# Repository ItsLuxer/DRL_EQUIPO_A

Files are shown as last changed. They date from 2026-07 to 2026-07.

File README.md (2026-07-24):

# 🚀 DRL Equipo A

¡Hola! 😁 Somos estudiantes del **Centro de Enseñanza Técnica Industrial (CETI)**, actualmente cursando la asignatura de **Control I**.

<p align="justify">
El objetivo principal de este proyecto es el diseño y construcción de un sistema aéreo no tripulado (dron) desde cero. Para fundamentar el desarrollo y comprender la integración de sus subsistemas, hemos iniciado este proceso mediante la ingeniería inversa de un dron comercial. Este análisis técnico nos ha permitido identificar, documentar y comprender la arquitectura, los componentes electrónicos y los protocolos de comunicación críticos necesarios para el funcionamiento y control de vuelo de un dron.
</p>

## 🛠 Equipo de Gestión y Desarrollo

Este proyecto es posible gracias al trabajo colaborativo del siguiente equipo de ingenieros:

* **Ingeniero Control:** José Eduardo
* **Ingeniero Mecánico:** Héctor Manuel
* **Ingeniero Eléctrico:** Héctor Cruz
* **Ingeniero Software:** José Alberto
* **Ingeniero Comunicaciones:** Darío Ibarra

---

# 📄 Prototipo

<div align="center">
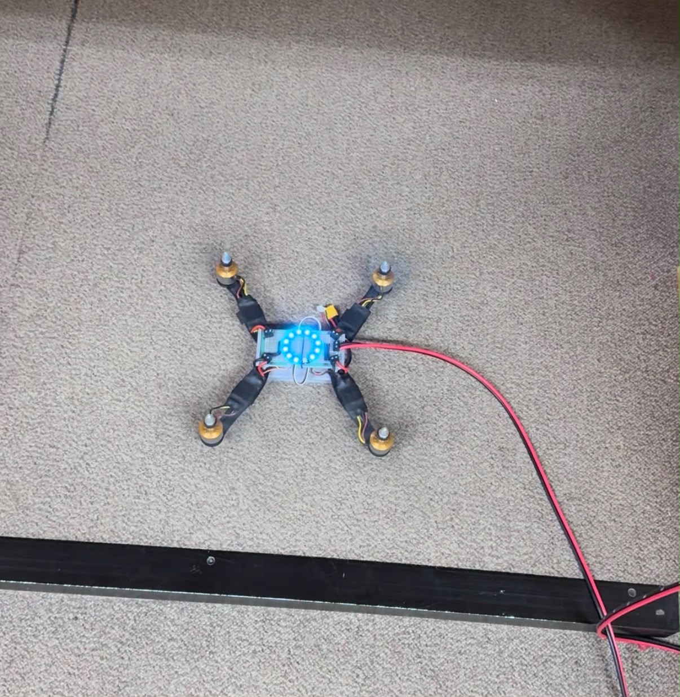
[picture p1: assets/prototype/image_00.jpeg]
  
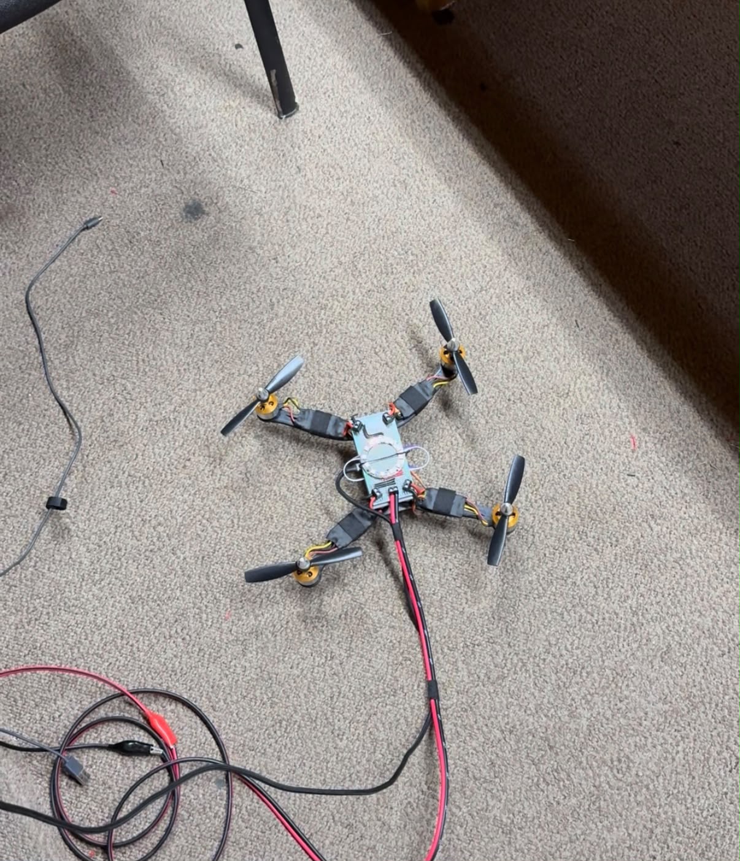
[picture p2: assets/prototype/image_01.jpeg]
  
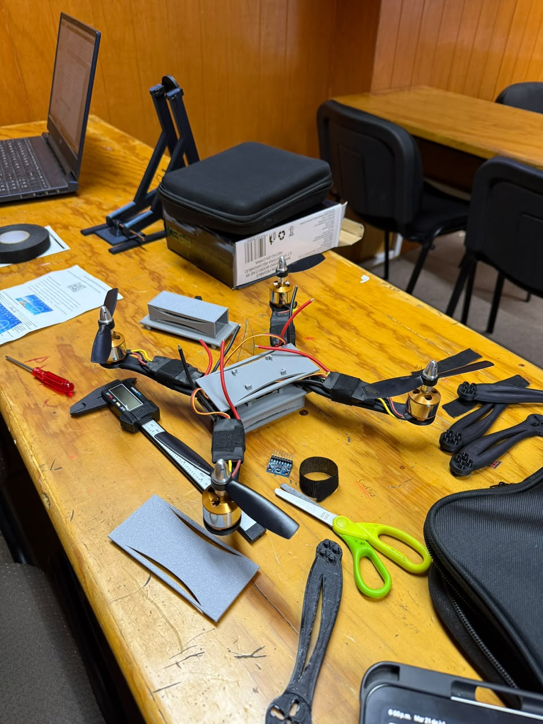
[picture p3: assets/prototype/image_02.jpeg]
  
</div>

---

# 🔩 Componentes del Dron

A continuación se documentan los componentes electrónicos y mecánicos utilizados en el desarrollo del prototipo propio.

<table>
  <tr>
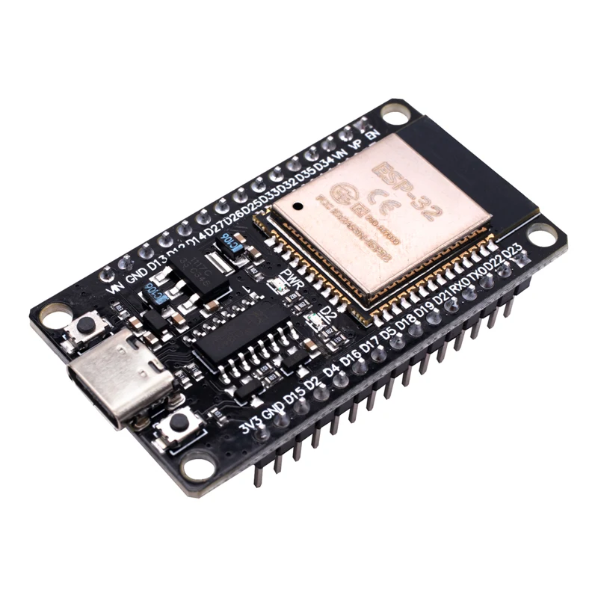
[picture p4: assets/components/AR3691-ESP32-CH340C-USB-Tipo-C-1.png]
    <td align="center" width="250"></td>
    <td>
      <b>ESP32 - Base</b><br>
      <ul>
        <li><b>Modelo:</b> ESP32 DEVKIT V1</li>
        <li><b>Puerto:</b> Micro USB o USB-C (según versión)</li>
        <li><b>Chip USB-Serial:</b> CP2102 (Micro USB) / CH340 (USB-C)</li>
        <li><b>Núcleos:</b> 2 (Tensilica Xtensa 32-bit LX6)</li>
        <li><b>Frecuencia de reloj:</b> hasta 240 MHz</li>
        <li><b>Desempeño:</b> hasta 600 DMIPS</li>
        <li><b>Voltaje de alimentación (USB):</b> 5 V DC</li>
        <li><b>Voltaje de E/S:</b> 3.3 V DC</li>
        <li><b>Consumo en modo suspensión:</b> 5 µA</li>
        <li><b>Pines físicos:</b> 30 (24 GPIO digitales)</li>
        <li><b>ADC:</b> 2 canales de 12 bits (SAR), hasta 18 canales</li>
        <li><b>Conectividad:</b> WiFi 802.11 b/g/n/e/i (150 Mbit/s @ 2.4 GHz) + Bluetooth 4.2 BR/EDR/BLE, antena en PCB</li>
        <li><b>Memoria:</b> 448 KB ROM, 520 KB SRAM, 6 KB SRAM RTC, soporte QSPI multi-chip</li>
        <li><b>Seguridad:</b> IEEE 802.11 (WFA, WPA/WPA2, WAPI), cifrado por hardware AES, SHA-2, RSA, ECC, RNG</li>
        <li><b>Dimensiones:</b> 52 mm x 28.5 mm x 15 mm</li>
        <li><b>Peso:</b> 9 g</li>
      </ul>
    </td>
  </tr>
  <tr>
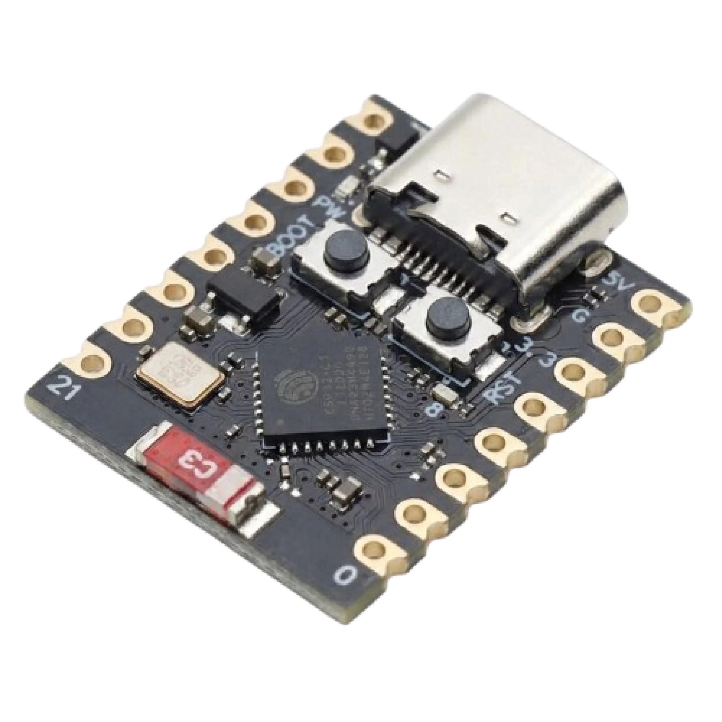
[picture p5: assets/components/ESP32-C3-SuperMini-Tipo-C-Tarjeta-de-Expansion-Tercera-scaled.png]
    <td align="center" width="250"></td>
    <td>
      <b>ESP32 - Aire</b><br>
      <ul>
        <li><b>Modelo:</b> ESP32-C3 Super Mini</li>
        <li><b>Chip:</b> ESP32-C3, 32-bit RISC-V, 160 MHz</li>
        <li><b>Puerto:</b> USB Tipo C</li>
        <li><b>Voltaje de operación:</b> 3 V a 3.6 V</li>
        <li><b>Rango de temperatura:</b> -40° a 85°C</li>
        <li><b>WiFi:</b> IEEE 802.11 b/g/n (2.4 GHz)</li>
        <li><b>Bluetooth:</b> Bluetooth 5, Bluetooth Mesh</li>
        <li><b>Memoria:</b> 384 KB ROM, 400 KB SRAM, 4 MB flash</li>
        <li><b>Periféricos:</b> 1× I2C, 1× SPI, 2× UART, 11× PWM, 4× ADC</li>
        <li><b>Dimensiones:</b> 22.5 mm × 18 mm</li>
        <li><b>Peso:</b> 3.05 g</li>
      </ul>
    </td>
  </tr>
  <tr>
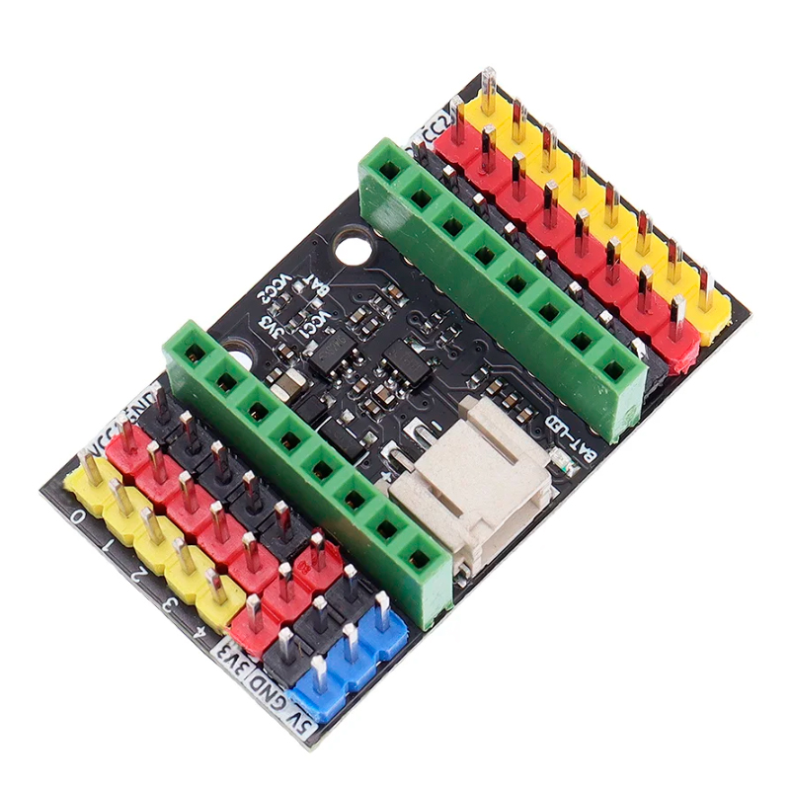
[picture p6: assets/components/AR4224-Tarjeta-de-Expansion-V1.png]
    <td align="center" width="250"></td>
    <td>
      <b>Tarjeta de Expansión</b><br>
      <ul>
        <li><b>Entrada/Fuente:</b> USB Tipo C / Batería de Litio 3.7 V</li>
        <li><b>Voltajes de salida:</b> 5 V y 3.3 V</li>
        <li><b>Voltaje de batería:</b> 3.7 V</li>
        <li><b>Dimensiones:</b> 37.4 mm × 22.7 mm</li>
        <li><b>Peso:</b> 8 g</li>
      </ul>
    </td>
  </tr>
  <tr>
    <td align="center" width="250"></td>
    <td>
      <b>Motor Brushless</b><br>
      <ul>
        <li><b>Modelo:</b> A2212/6 T</li>
        <li><b>Motor KV (RPM / V):</b> KV2200</li>
        <li><b>RPM / V:</b> 2200 KV (2200 revoluciones por minuto por cada volt suministrado)</li>
        <li><b>Voltaje:</b> 7.2 V a 12 V</li>
        <li><b>Corriente:</b> 12 A / 60 s</li>
        <li><b>Eficiencia máxima:</b> 80%</li>
        <li><b>Corriente máxima de eficiencia:</b> 4 ~ 10 A (> 75%)</li>
        <li><b>Corriente sin carga:</b> 10 V / 0.5 A</li>
        <li><b>Tamaño de motor (con eje):</b> 27.5 mm x 38.5 mm</li>
        <li><b>Diámetro del eje:</b> 3.17 mm (3.2 mm)</li>
        <li><b>Longitud del diámetro:</b> 11.5 mm</li>
        <li><b>Peso:</b> 47 g</li>
      </ul>
    </td>
  </tr>
  <tr>
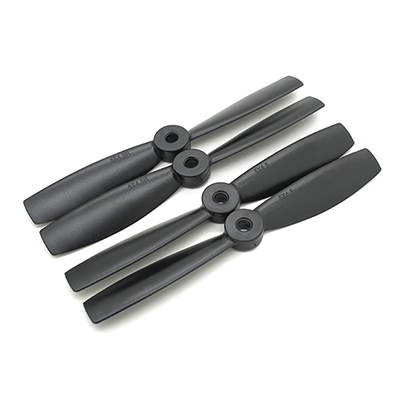
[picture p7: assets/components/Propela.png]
    <td align="center" width="250"></td>
    <td>
      <b>Propela</b><br>
      <ul>
        <li><b>Color:</b> Negro</li>
        <li><b>Orificio de eje:</b> 5 mm</li>
        <li><b>Configuración del paquete:</b> 4 piezas (2 CW / 2 CCW)</li>
        <li><b>Dimensiones:</b> 5 x 4.5"</li>
        <li><b>Peso:</b> 3.8 g c/u</li>
      </ul>
    </td>
  </tr>
  <tr>
    <td align="center" width="250"></td>
    <td>
      <b>ESC</b><br>
      <ul>
        <li><b>Modelo:</b> ESC 30A Driver Motor Brushless</li>
        <li><b>Voltaje de entrada:</b> 2–4 celdas de litio o 5–12 celdas NiCd/NiMH</li>
        <li><b>Corriente continua:</b> 30 A</li>
        <li><b>Corriente máxima (ráfaga):</b> 40 A</li>
        <li><b>Salida BEC:</b> 5 V / 2 A</li>
        <li><b>Frecuencia de trabajo:</b> 50–60 Hz (señal PWM)</li>
        <li><b>RPM máximas soportadas:</b> 210,000 RPM (2 polos), 70,000 RPM (6 polos), 35,000 RPM (12 polos)</li>
        <li><b>Señal de control:</b> PWM estándar (1000–2000 µs)</li>
        <li><b>Tamaño:</b> 57 mm × 25 mm × 8 mm</li>
        <li><b>Peso neto:</b> 27 g</li>
      </ul>
    </td>
  </tr>
  <tr>
    <td align="center" width="250"></td>
    <td>
      <b>Batería</b><br>
      <ul>
        <li><b>Voltaje:</b> 11.1 V</li>
        <li><b>Celdas:</b> 3S</li>
        <li><b>Capacidad de descarga:</b> 30 a 60C</li>
        <li><b>Corriente:</b> 1,400 mAh</li>
        <li><b>Descarga continua:</b> 25C</li>
        <li><b>Tamaño:</b> 85.7 mm x 29.8 mm x 20.2 mm</li>
        <li><b>Peso neto:</b> 125 g</li>
      </ul>
    </td>
  </tr>
  <tr>
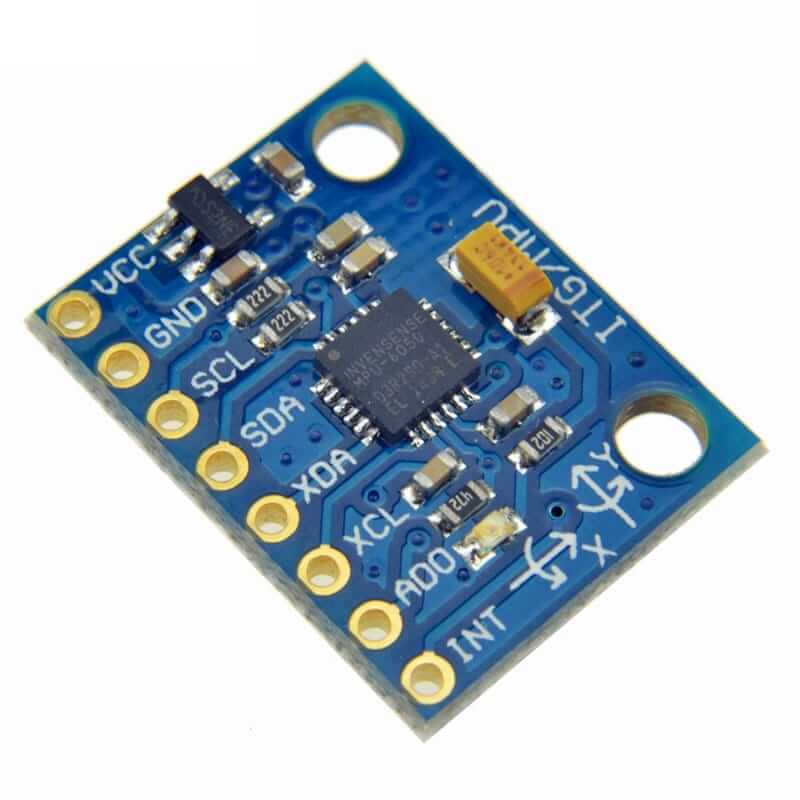
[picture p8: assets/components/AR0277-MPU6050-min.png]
    <td align="center" width="250"></td>
    <td>
      <b>Módulo Giroscopio/Acelerómetro</b><br>
      <ul>
        <li><b>Módulo:</b> MPU6050 6 Grados de libertad.</li>
        <li><b>Voltaje de funcionamiento:</b> 3.3 V a 5 V</li>
        <li><b>Chip:</b> MPU-6050</li>
        <li><b>Grados de libertad (DoF):</b> 6</li>
        <li><b>Protocolo de comunicación:</b> I2C</li>
        <li><b>Convertidor analógico a digital:</b> 16 bits en todos los ejes</li>
        <li><b>Rangos:</b>
          <ul>
            <li><b>Giroscopio:</b> ±250, ±500, ±1000 y ±2000 °/s (dps)</li>
            <li><b>Acelerómetro:</b> ±2, ±4, ±8 y ±16 g</li>
          </ul>
        </li>
        <li><b>Dimensiones:</b> 40 mm x 25 mm x 5 mm</li>
        <li><b>Peso:</b> 3 g</li>
      </ul>
    </td>
  </tr>
  <tr>
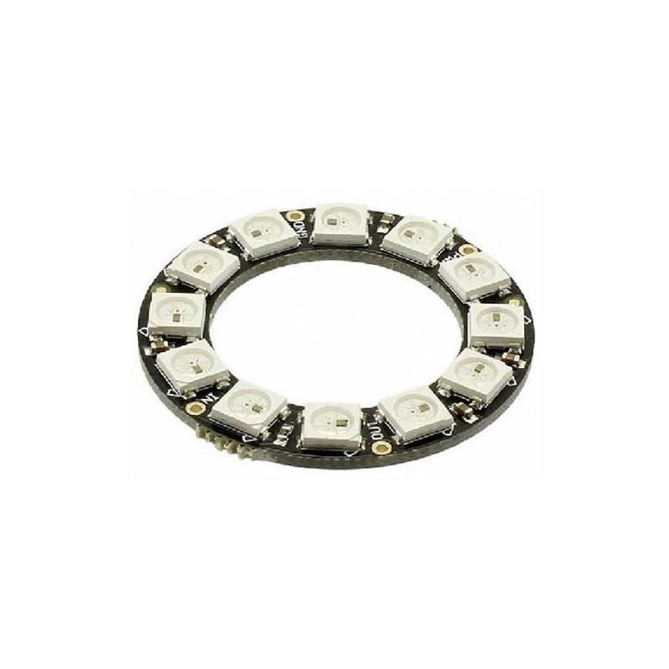
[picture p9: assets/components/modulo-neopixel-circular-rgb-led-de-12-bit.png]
    <td align="center" width="250"></td>
    <td>
      <b>Iluminación Neopixel</b><br>
      <ul>
        <li><b>Chip controlador:</b> WS2812B</li>
        <li><b>Voltaje de operación:</b> 5 V</li>
        <li><b>Número de LEDs:</b> 12 piezas</li>
        <li><b>Consumo por píxel:</b> 18 mA</li>
        <li><b>Velocidad de transmisión de datos:</b> hasta 800 Kbps</li>
        <li><b>Colores por píxel:</b> 16,777,216 (256 niveles por canal RGB)</li>
        <li><b>Frecuencia de escaneo:</b> ≥ 400 Hz/s</li>
        <li><b>Interfaz:</b> cascada en serie (una línea de señal)</li>
        <li><b>Distancia de transmisión entre puntos:</b> < 5 m sin circuito adicional</li>
        <li><b>Protección:</b> polaridad inversa integrada</li>
        <li><b>Diámetro interior:</b> 35.5 mm</li>
        <li><b>Diámetro exterior:</b> 50 mm</li>
        <li><b>Peso:</b> 6 g</li>
      </ul>
    </td>
  </tr>
</table>

---

## 📄 Planos

A continuación se documentan los planos técnicos utilizados en el desarrollo del prototipo.

<div align="center">

### Plano del Chasis


### Distribución de Componentes


</div>

---

# 🚁 Compilación de Betaflight 4.5.2 para STM32F411 (BlackPill)

**Objetivo:** Compilar un firmware funcional de Betaflight 4.5.2 para una placa de desarrollo genérica STM32F411 (BlackPill) en un entorno Windows utilizando MSYS2, evitando errores de estructura de directorios y dependencias de Python.

---

## 📋 Requisitos Previos
1. Sistema operativo **Windows**.
2. Entorno **MSYS2** instalado.
3. Consola **UCRT64** de MSYS2 abierta. Todo el proceso se realizará exclusivamente en esta terminal.

---

## 🛠️ Paso 1: Preparación del entorno y dependencias
Antes de descargar el código, es necesario asegurar que el sistema cuenta con todas las herramientas necesarias para la compilación y la ejecución de scripts internos.

```bash
# 1. Actualizar el sistema base de MSYS2
pacman -Syu

# 2. Instalar Git, Make, Unzip y Python3
pacman -S git make unzip python3
```

---

## 📥 Paso 2: Descarga del código fuente de Betaflight
Crearemos un directorio de trabajo limpio en la raíz del disco duro y descargaremos la versión exacta del código que vamos a compilar.

```bash
# 1. Navegar a la raíz y crear la carpeta de trabajo
cd /c/
mkdir betaflight
cd betaflight

# 2. Clonar el repositorio oficial (incluyendo submódulos)
git clone --recursive https://github.com/betaflight/betaflight.git betaflight-4.5.2

# 3. Entrar a la carpeta descargada
cd betaflight-4.5.2

# 4. Cambiar a la rama de la versión estable 4.5.2
git checkout -b release-4.5.2 tags/4.5.2
```

---

## ⚙️ Paso 3: Instalación de la cadena de herramientas (ARM SDK)
Betaflight requiere una versión específica del compilador GCC cruzado para arquitecturas ARM. Descargaremos esta herramienta y ajustaremos su directorio.

```bash
# 1. Descargar y extraer el compilador GCC ARM automáticamente
make arm_sdk_install

# 2. Corregir el error de anidación de carpetas (mover archivos un nivel arriba)
mv tools/gcc-arm-none-eabi-10.3-2021.10/gcc-arm-none-eabi-10.3-2021.10/* tools/gcc-arm-none-eabi-10.3-2021.10/

# 3. Añadir el compilador a las variables de entorno (PATH)
export PATH=$PATH:/c/betaflight/betaflight-4.5.2/tools/gcc-arm-none-eabi-10.3-2021.10/bin
```

---

## 📂 Paso 4: Obtención de la configuración personalizada
Para que Betaflight reconozca la placa BlackPill, necesitamos un perfil de hardware (target) que defina los pines y puertos de la STM32F411.

```bash
# 1. Salir momentáneamente a la carpeta principal de trabajo
cd /c/betaflight

# 2. Clonar el repositorio comunitario con la configuración de la placa
git clone https://github.com/anlgncr/custom-betaflight-board.git
```

---

## 🧩 Paso 5: Integración en la estructura de Betaflight 4.5+
A partir de la versión 4.5, el sistema de compilación cambió. Las configuraciones de hardware ya no se ubican en `src/main/target`, sino que utilizan el sistema de configuración unificado.

```bash
# 1. Regresar a la carpeta del código fuente de Betaflight
cd betaflight-4.5.2

# 2. Crear el directorio para configuraciones personalizadas (si no existe)
mkdir -p src/config/configs

# 3. Copiar la configuración de la BlackPill a la nueva ruta
cp -r /c/betaflight/custom-betaflight-board/BLACKPILL src/config/configs/
```

---

## 🚀 Paso 6: Compilación del Firmware
Con el entorno limpio, el compilador configurado y la placa en la ruta correcta, procederemos a compilar.

> ⚠️ **Importante:** En la versión 4.5.2, para compilar configuraciones personalizadas, se debe utilizar el parámetro `CONFIG=` en lugar del antiguo `TARGET=`.

```bash
# 1. Limpiar el entorno de compilaciones o cachés anteriores
make clean

# 2. Iniciar la compilación final para la BlackPill
make CONFIG=BLACKPILL
```

---

## 🎉 Paso 7: Resultados y Flasheo
Si el proceso se realizó correctamente, la terminal finalizará sin errores y mostrará el uso de memoria (FLASH y RAM) del procesador. El archivo compilado listo para ser cargado en la placa se generará en la siguiente ruta:

```
/c/betaflight/betaflight-4.5.2/obj/betaflight_4.5.2_STM32F411_BLACKPILL.hex
```

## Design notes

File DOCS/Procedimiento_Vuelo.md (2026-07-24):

# Procedimiento de vuelo — Daltonics_Vuelo (despegue/aterrizaje por tecla)

Firmware Aire: `Firmware/Daltonics_Vuelo/Daltonics_Vuelo.ino` (ESP32-C3 SuperMini)
Firmware Tierra: `Firmware/Daltonics_Tierra/Daltonics_Tierra.ino` (con telemetría al operador)
Mando: `CONTROL/Control_Vuelo_Daltonics.m` (MATLAB)

**Telemetría**: el dron reporta a MATLAB a 10 Hz su roll/pitch, gas, modo y alertas
(emergencia, IMU caída, aterrizado) — se ve en la ventana del mando como "DRON >>".
El viejo `ESP32_PRUEBATIERRA` sigue sirviendo como respaldo, pero sin telemetría.

## Máquina de estados (campo A de la trama)

| A | Estado | Motores | LED |
|---|---|---|-----|
| 0 | DESARMADO | Apagados | Verde tenue |
| 1 | IDLE | Girando suave (1120 µs), sin despegar | Verde brillante |
| 2 | VUELO | Rampa 8 %/s hasta gas de hover + PID de actitud | Azul |
| 3 | ATERRIZAJE | Rampa automática -3.5 %/s hasta idle | Amarillo → celeste |
| — | EMERGENCIA (>45° de inclinación) | Apagados hasta desarmar (Q) y rearmar | Rojo |
| — | FAILSAFE (>500 ms sin señal) | Apagados | Naranja |

## Teclas (MATLAB)

`E` armar/idle · `T` despegue · `L` aterrizar · `Q` corte total ·
`W/S` trim de gas ±0.5 % · flechas roll/pitch · `A/D` yaw · `ESPACIO` nivelar

## Secuencia de esta noche

1. **Alimentación**: usar la **LiPo real**. La fuente de banco se cae de amperaje y
   puede resetear el ESP32 **con los motores armados**. Si igual usás la fuente,
   solo pruebas SIN hélices.
2. Encender el dron **quieto y nivelado**: al arrancar hace 3 s de calibración del
   giroscopio (LED violeta). No moverlo hasta que termine.
3. Espera los beeps de los ESC (LED ámbar, pulso mínimo 3 s).
4. **Prueba SIN hélices** (obligatoria la primera vez):
   - `E` → los 4 motores giran parejos en idle. Si uno no arranca, recalibrar ESCs.
   - `T` → inclinar el dron a mano y ver por Serial que el motor del lado que baja
     **sube** de PWM. Si es al revés, corregir signos antes de poner hélices.
   - `L` y `Q` → verificar rampa de bajada y corte.
5. **Primera prueba con hélices**: dron sujetado (banco o correas), a baja altura,
   sin gente cerca del plano de las hélices.
6. En hover, ajustar el gas con `W/S`: el 45 % inicial se midió con la fuente
   dudosa, así que el valor real con LiPo puede ser distinto.

## Ajuste del PID (en orden, sin hélices primero)

1. Subir `Kp_ang` hasta que empuje de regreso con fuerza al inclinar, sin oscilar.
2. Si tiembla al soltar, subir `Kd_ang`.
3. Solo al final, si queda "recostado", subir `Ki_ang` de a poco.

## Sin altímetro

El hover mantiene el dron **nivelado**, pero la altura es lazo abierto: deriva con
la batería descargándose. Compensar con `W/S`. Siguiente mejora sugerida: montar el
BME680 o un VL53L0X para lazo cerrado de altura.

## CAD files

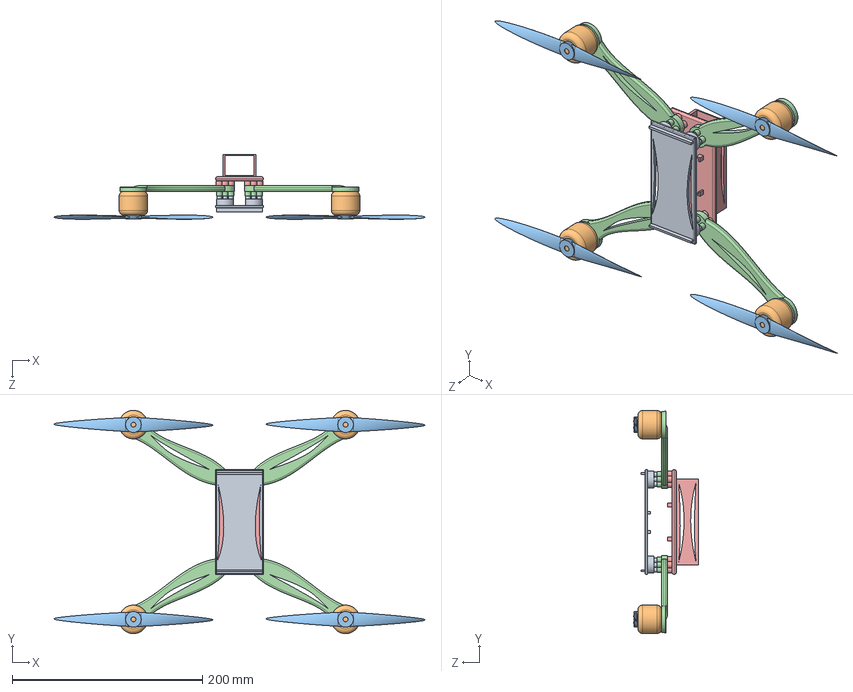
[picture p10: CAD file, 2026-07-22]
Dron semana 3 Mejorado/Ensamblaje Dron semana 3.SLDASM
389.7 x 234.5 x 67.9 mm
Molde de la base Dron semana 3
Brazos del dron semana 3 x 2
Elises de 16 cm x 4
molde del Motor x 4
Segundo piso

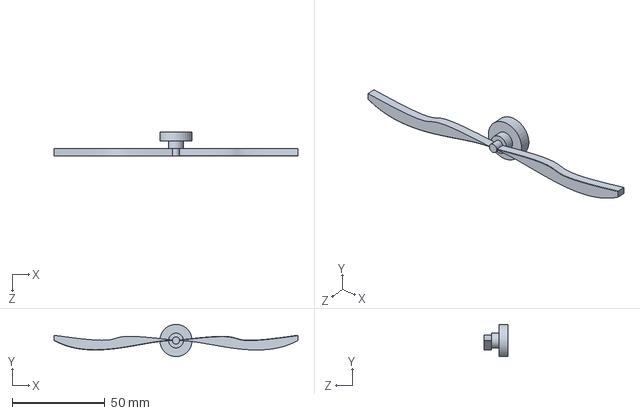
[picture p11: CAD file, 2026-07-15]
Diseños MK1/Dron Simulacion para Matlap/Elises.SLDPRT
131.6 x 17.4 x 13.0 mm

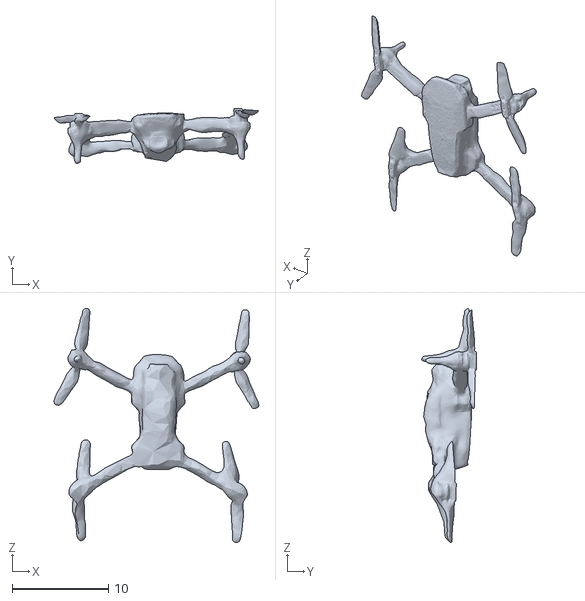
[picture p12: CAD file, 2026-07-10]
Dron_Digital/MATLAB_DRIVE/DronNaya.STL
21.3 x 5.76 x 24.4

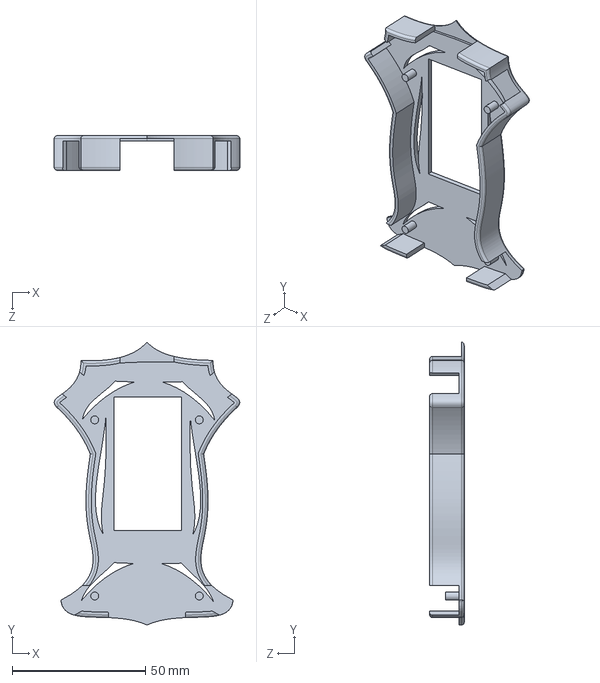
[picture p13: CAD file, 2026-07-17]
Estructura base/FRONTPANEL.SLDPRT
69.7 x 106.3 x 13.0 mm

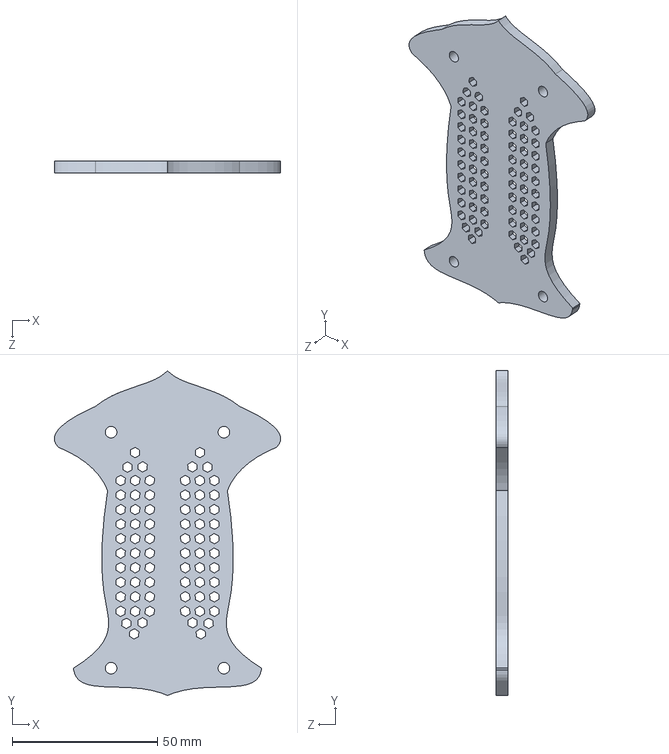
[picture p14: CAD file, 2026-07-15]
Diseños MK1/Dron Simulacion para Matlap/DronSimulacion.SLDPRT
77.9 x 111.8 x 4.00 mm

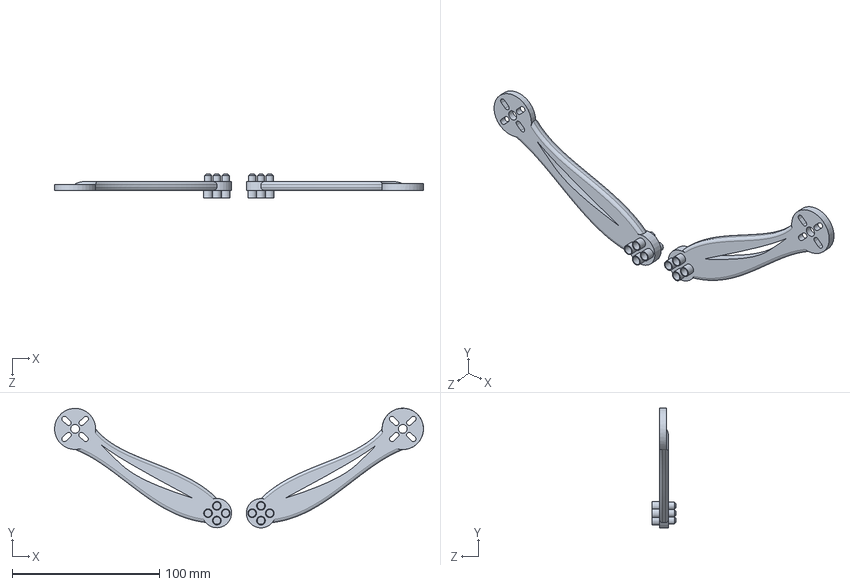
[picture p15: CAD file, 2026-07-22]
Dron semana 3 Mejorado/Brazos del dron semana 3.SLDPRT
250.9 x 81.4 x 16.0 mm

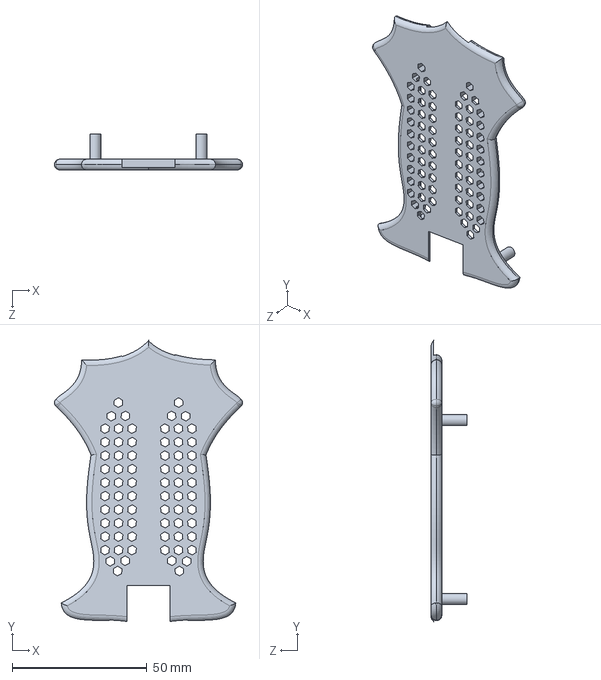
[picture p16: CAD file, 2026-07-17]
Estructura base/Prueba 2.SLDPRT
69.7 x 104.1 x 13.3 mm

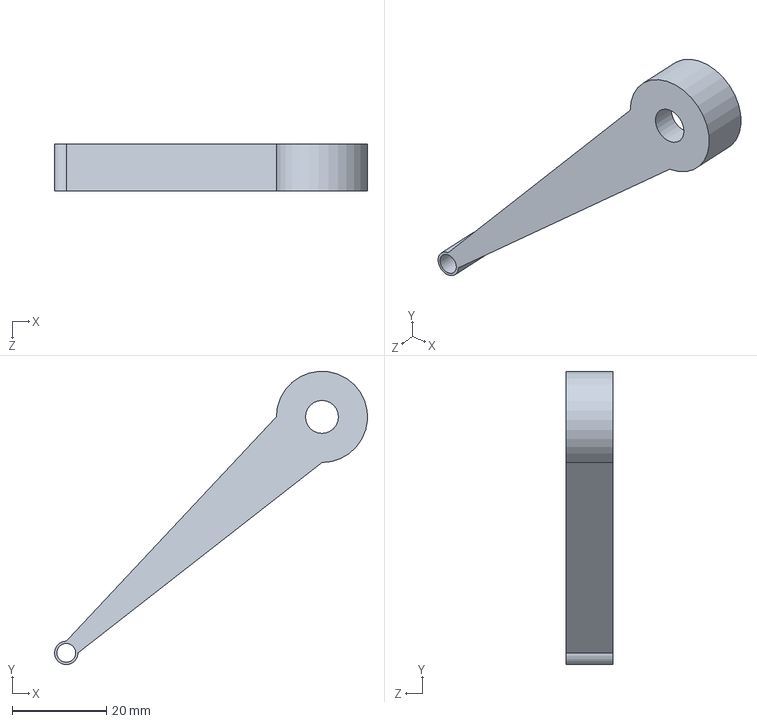
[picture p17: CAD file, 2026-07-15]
Diseños MK1/Dron Simulacion para Matlap/Brazos del dron.SLDPRT
66.5 x 62.3 x 10.0 mm

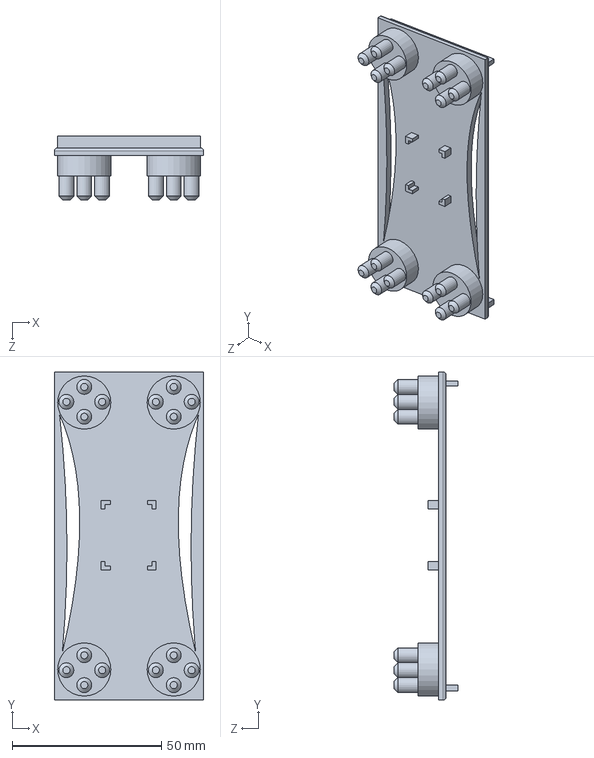
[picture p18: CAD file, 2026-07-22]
Dron semana 3 Mejorado/Segundo piso.SLDPRT
50.0 x 110.0 x 21.5 mm

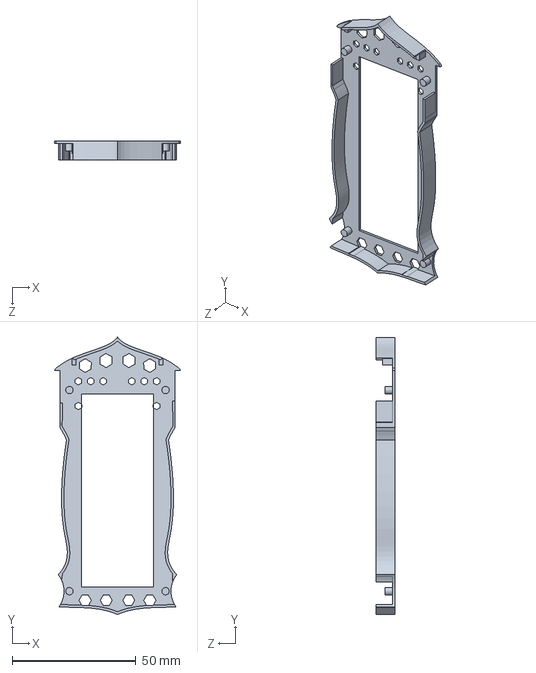
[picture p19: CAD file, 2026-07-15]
Diseños MK1/Dron Simulacion para Matlap/DrpnBASE.SLDPRT
51.0 x 111.8 x 7.60 mm

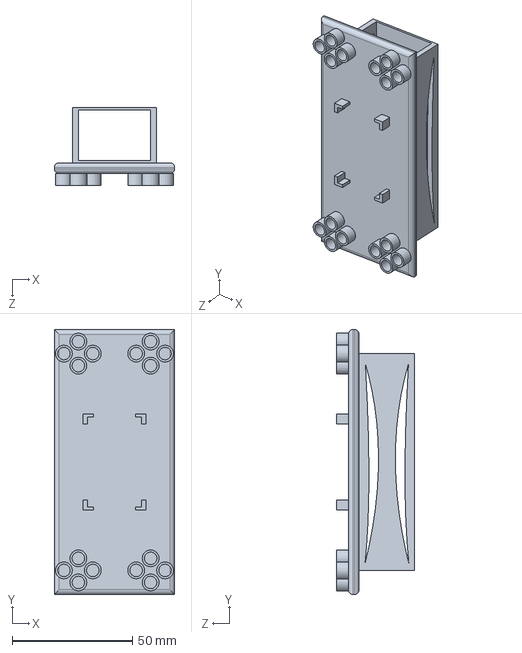
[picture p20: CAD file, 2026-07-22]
Dron semana 3 Mejorado/Molde de la base Dron semana 3.SLDPRT
50.0 x 110.0 x 32.5 mm

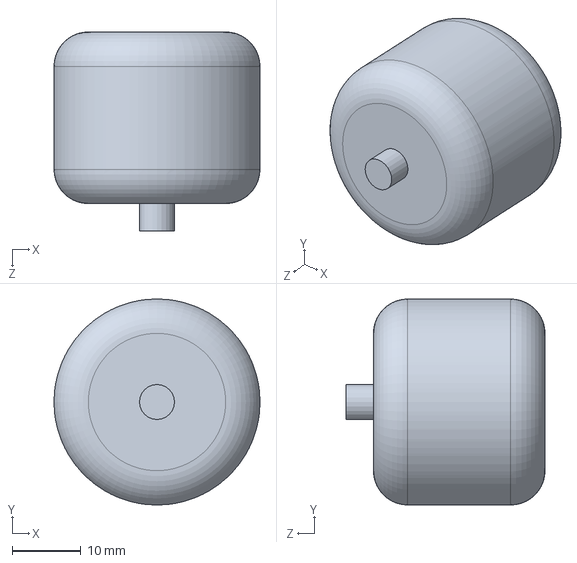
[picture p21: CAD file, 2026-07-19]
Dron semana 3 Mejorado/molde del Motor.SLDPRT
30.0 x 30.0 x 29.0 mm

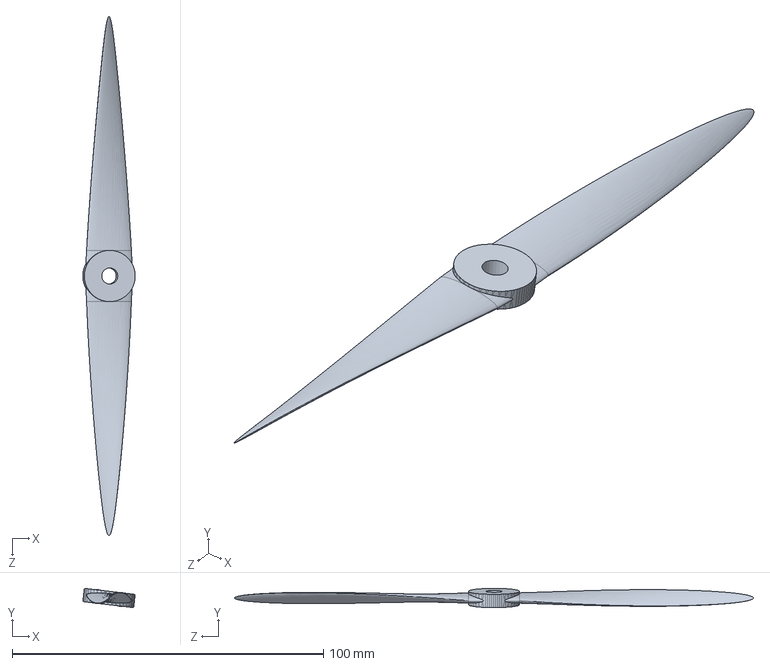
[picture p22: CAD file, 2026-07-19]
Dron semana 3 Mejorado/Elises de 16 cm.SLDPRT
16.9 x 6.21 x 166.8 mm

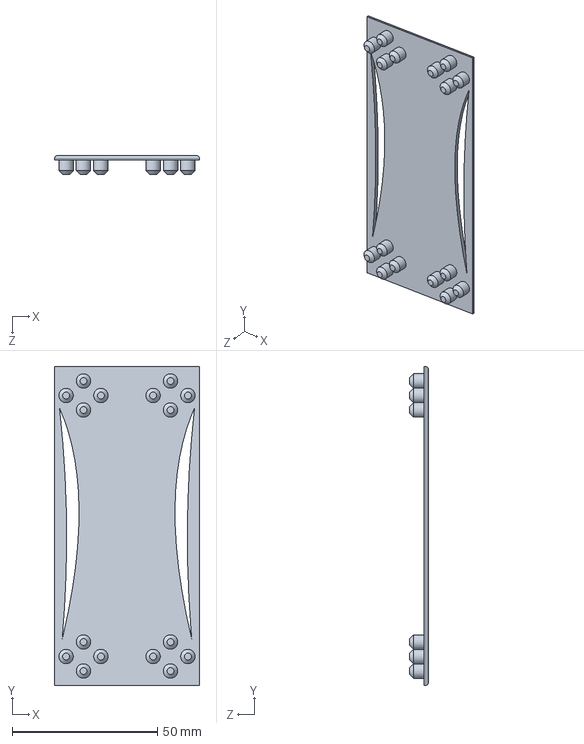
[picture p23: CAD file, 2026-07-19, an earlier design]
Dron Semana 3/Segundo piso.SLDPRT
50.0 x 110.0 x 6.50 mm

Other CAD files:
Dron Semana 3/Ensamblaje Dron semana 3.SLDASM
Dron Semana 3/Molde de la base Dron semana 3.SLDPRT
Dron Semana 3/Brazos del dron semana 3.SLDPRT

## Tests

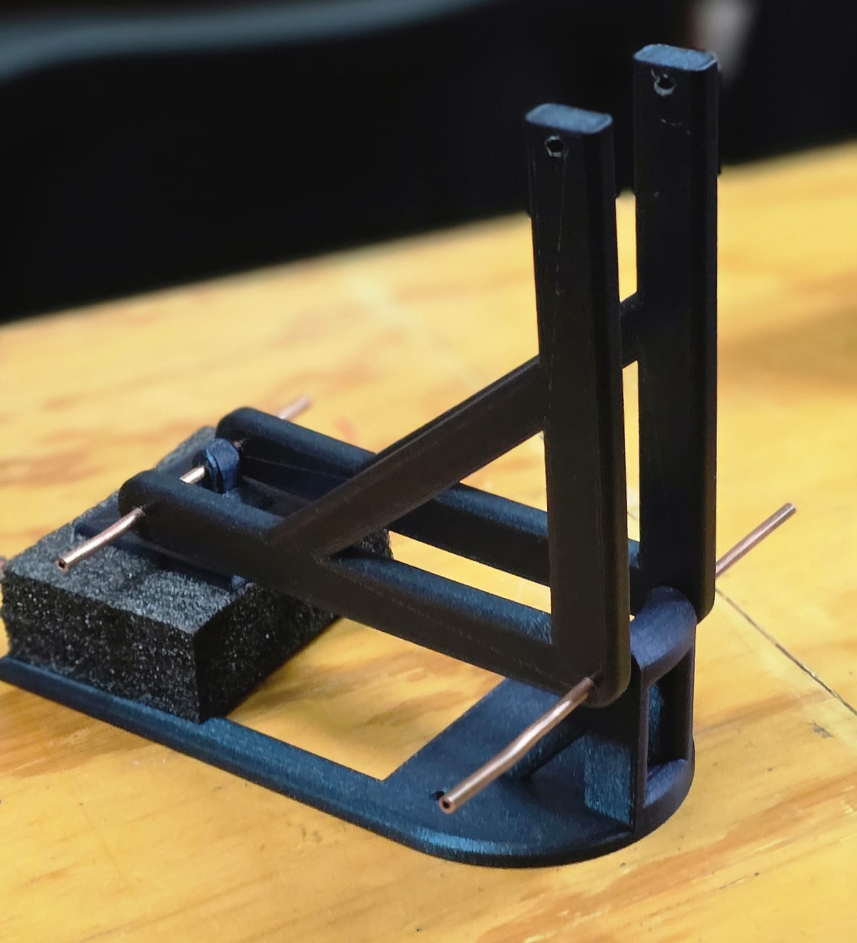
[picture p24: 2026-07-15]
Banco de Pruebas para los motores del dron/Banco de Prubeas.jpeg

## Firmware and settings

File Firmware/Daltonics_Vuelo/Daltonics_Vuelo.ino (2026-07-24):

// =========================================================================
// Daltonics_Vuelo.ino — Firmware de vuelo con MAQUINA DE ESTADOS
// (ESP32-C3 SuperMini, unidad AIRE — Escuderia Daltonics)
//
// Evolucion de Daltonics_Aire.ino. Agrega:
//   1) Calibracion automatica del giroscopio al encender (bias) — el dron
//      DEBE estar quieto y nivelado durante los primeros ~3 segundos.
//   2) Maquina de estados comandada desde tierra por el campo A del
//      protocolo (antes solo 0/1, ahora 0-3):
//        A=0  DESARMADO   -> motores apagados
//        A=1  IDLE        -> motores girando suave (IDLE_US) SIN despegar
//        A=2  VUELO       -> despegue con rampa suave hacia el throttle
//                            de hover + PID de actitud (se queda nivelado)
//        A=3  ATERRIZAJE  -> rampa descendente automatica hasta idle
//   3) Rampa (slew-rate) de throttle: nunca hay saltos bruscos de gas.
//
// PROTOCOLO: mismo PaqueteControl de siempre. ESP32_PRUEBATIERRA.ino NO
// necesita cambios (su parser del campo A ya acepta 0-3). En tierra usar
// CONTROL/Control_Vuelo_Daltonics.m (teclas E/T/L/Q).
//
// *** SIN ALTIMETRO: el hover mantiene NIVEL (roll/pitch) pero la ALTURA
// *** es lazo abierto. El gas de hover se ajusta fino con W/S desde
// *** MATLAB. Primera prueba: sosten el dron con la mano (lejos de las
// *** helices) o atado, a baja altura, y con la LiPo real — la fuente de
// *** banco puede resetear el ESP32 con los motores armados.
//
// Checklist antes de volar (una sola vez):
//   1) Calibrar ESCs (Firmware/Calibrar_ESCs).
//   2) SIN HELICES: armar (E), inclinar a mano y confirmar por Serial que
//      el motor del lado que baja es el que SUBE de PWM.
//   3) Verificar que IDLE_US hace girar los 4 motores parejos sin empuje.
// =========================================================================

#include <Arduino.h>
#include <WiFi.h>
#include <esp_now.h>
#include <ESP32Servo.h>
#include <Adafruit_NeoPixel.h>
#include <Wire.h>
#include <Adafruit_MPU6050.h>
#include <Adafruit_Sensor.h>

// ================= PROTOCOLO =================
struct __attribute__((packed)) PaqueteControl {
    uint16_t throttle;   // 1000-2000 us (en VUELO: gas objetivo de hover)
    uint16_t roll;       // 1000-2000 us, centro 1500
    uint16_t pitch;      // 1000-2000 us, centro 1500
    uint16_t yaw;        // 1000-2000 us, centro 1500 (yaw-RATE)
    uint8_t  armable;    // MODO: 0=desarmado 1=idle 2=vuelo 3=aterrizaje
};

enum Modo : uint8_t { M_DESARMADO = 0, M_IDLE = 1, M_VUELO = 2, M_ATERRIZAJE = 3 };

PaqueteControl comandosDron = {1000, 1500, 1500, 1500, M_DESARMADO};
unsigned long ultimaVezRecibido = 0;
const unsigned long TIMEOUT_FAILSAFE = 500; // ms sin señal -> failsafe

// ================= TELEMETRIA HACIA TIERRA (dron -> operador) =================
// El dron aprende el MAC de Tierra del primer paquete recibido y le manda
// su estado a 10 Hz. Tierra lo reenvia por USB a MATLAB como "TL,...".
struct __attribute__((packed)) PaqueteTelemetria {
    float   rollDeg;   // actitud estimada
    float   pitchDeg;
    float   thrPct;    // gas aplicado ahora (thrActual)
    uint8_t modo;      // 0-3
    uint8_t flags;     // b0=emergencia b1=failsafe b2=aterrizado b3=mpuOK
};
uint8_t macTierra[6];
volatile bool macTierraCapturada = false;
bool peerTierraListo = false;
unsigned long ultimoTelem = 0;

void onDataRecv(const esp_now_recv_info_t *recv_info, const uint8_t *incomingData, int len) {
    if (len == sizeof(PaqueteControl)) {
        memcpy(&comandosDron, incomingData, sizeof(comandosDron));
        ultimaVezRecibido = millis();
        if (!macTierraCapturada) {
            memcpy(macTierra, recv_info->src_addr, 6);
            macTierraCapturada = true;
        }
    }
}

// ================= MPU6050 (pines C3 SuperMini) =================
#define SDA_PIN 20
#define SCL_PIN 21
Adafruit_MPU6050 mpu;
bool mpuOK = false;

// Bias del giroscopio, medido en la calibracion de arranque
float gyroBiasX = 0, gyroBiasY = 0, gyroBiasZ = 0;
bool imuCalibrada = false;

// ================= NEOPIXEL =================
#define PIN_NEOPIXEL 10
#define NUM_LEDS 12
Adafruit_NeoPixel aro(NUM_LEDS, PIN_NEOPIXEL, NEO_GRB + NEO_KHZ800);

// ================= MOTORES (pines/desfases confirmados) =================
Servo motor1, motor2, motor3, motor4;
const int pinM1 = 1, pinM2 = 2, pinM3 = 3, pinM4 = 4;
// M1=delantero-izq  M2=delantero-der  M3=trasero-izq  M4=trasero-der

int desfaseM1 = -25;
int desfaseM2 = 0;
int desfaseM3 = 0;
int desfaseM4 = 0;

const int PWM_MIN_US  = 1000;
const int PWM_MAX_US  = 2000;
const int IDLE_US     = 1120;  // motores girando suave, SIN empuje de despegue
                               // (ajustar: debe girar parejo en los 4 sin que
                               //  el dron "aligere" sobre el piso)

// ================= RAMPAS DE THROTTLE (en % de gas, 0-100) =================
const float RAMPA_SUBIDA_PCT_S  = 8.0f;   // despegue: sube 8%/s (susave)
const float RAMPA_BAJADA_PCT_S  = 12.0f;  // correccion hacia abajo en vuelo
const float RAMPA_ATERR_PCT_S   = 3.5f;   // aterrizaje: baja 3.5%/s
const float PCT_CORTE_ATERR     = 25.0f;  // debajo de esto ya no sustenta ->
                                          // corta a idle (aterrizado)
float thrActual = 0.0f;                    // % de gas aplicado ahora mismo
bool  aterrizado = false;                  // subestado de M_ATERRIZAJE

// ================= GEOMETRIA / EMPUJE (igual que Daltonics_Aire) =================
float DX   = 0.1061f;
float DY   = 0.1061f;
float TMAX = 2.73f;
float CYAW = 0.013f;

// ================= GANANCIAS PID =================
// Punto de partida CONSERVADOR (~mitad del gemelo digital) para el primer
// contacto real: mejor blando que sobre-corregir y voltear.
//
// GANANCIAS DEL GEMELO DIGITAL (DALTONICS_parametros.m, tuneadas en
// simulacion para el dron de 530 g) — meta a la que subir gradualmente
// si la prueba de banco sin helices responde sana:
//   Kp_ang = 0.077   Ki_ang = 0.019   Kd_ang = 0.023   N = 40
//   Kp_yaw = 0.052   Ki_yaw = 0.022
// Orden de tuneo: Kp primero, Kd si oscila, Ki al final y de a poco
// (si se activa Ki, agregar limite al integrador / anti-windup).
float Kp_ang = 0.035f, Ki_ang = 0.0f, Kd_ang = 0.010f, N_filt = 20.0f;
float Kp_yaw = 0.020f, Ki_yaw = 0.0f;

// ================= PID 2-DOF (roll/pitch) y PI (yaw-rate) =================
struct PID2DOF {
    float Kp, Ki, Kd, N;
    float integ = 0, dFilt = 0, prevMeas = 0;
    bool primed = false;
    float update(float ref, float meas, float dt) {
        if (!primed) { prevMeas = meas; primed = true; }
        float error = ref - meas;
        integ += Ki * error * dt;
        float rawDeriv = (meas - prevMeas) / dt;
        dFilt += (rawDeriv - dFilt) * constrain(N * dt, 0.0f, 1.0f);
        prevMeas = meas;
        return Kp * error + integ - Kd * dFilt;
    }
    void reset() { integ = 0; dFilt = 0; primed = false; }
};

struct PIControlador {
    float Kp, Ki;
    float integ = 0;
    float update(float ref, float meas, float dt) {
        float error = ref - meas;
        integ += Ki * error * dt;
        return Kp * error + integ;
    }
    void reset() { integ = 0; }
};

PID2DOF pidRoll, pidPitch;
PIControlador pidYaw;

// ================= ESTIMACION DE ACTITUD =================
float rollEst = 0, pitchEst = 0; // rad
const float ALPHA = 0.98f;

// ================= MEZCLADORA =================
float Mix[4][4];

void invertir4x4(float A[4][4], float Inv[4][4]) {
    float aug[4][8];
    for (int i = 0; i < 4; i++) {
        for (int j = 0; j < 4; j++) aug[i][j] = A[i][j];
        for (int j = 0; j < 4; j++) aug[i][4 + j] = (i == j) ? 1.0f : 0.0f;
    }
    for (int col = 0; col < 4; col++) {
        int piv = col;
        for (int r = col + 1; r < 4; r++)
            if (fabs(aug[r][col]) > fabs(aug[piv][col])) piv = r;
        if (piv != col) for (int j = 0; j < 8; j++) { float t = aug[col][j]; aug[col][j] = aug[piv][j]; aug[piv][j] = t; }
        float d = aug[col][col];
        for (int j = 0; j < 8; j++) aug[col][j] /= d;
        for (int r = 0; r < 4; r++) {
            if (r == col) continue;
            float f = aug[r][col];
            for (int j = 0; j < 8; j++) aug[r][j] -= f * aug[col][j];
        }
    }
    for (int i = 0; i < 4; i++)
        for (int j = 0; j < 4; j++) Inv[i][j] = aug[i][4 + j];
}

void construirMezcladora() {
    float A[4][4] = {
        { 1,     1,     1,     1   },
        { DY,   -DY,    DY,   -DY  },
        {-DX,   -DX,    DX,    DX  },
        {-CYAW,  CYAW,  CYAW, -CYAW}
    };
    invertir4x4(A, Mix);
}

float mapFloat(float x, float inMin, float inMax, float outMin, float outMax) {
    return (x - inMin) * (outMax - outMin) / (inMax - inMin) + outMin;
}

// ================= SETPOINTS =================
void leerSetpoints(float &thrPct, float &rollRef, float &pitchRef, float &yawRateRef) {
    thrPct     = constrain(map(comandosDron.throttle, 1000, 2000, 0, 100), 0, 100);
    rollRef    = (constrain((int)comandosDron.roll,  1000, 2000) - 1500) / 500.0f * 25.0f  * DEG_TO_RAD;
    pitchRef   = (constrain((int)comandosDron.pitch, 1000, 2000) - 1500) / 500.0f * 25.0f  * DEG_TO_RAD;
    yawRateRef = (constrain((int)comandosDron.yaw,   1000, 2000) - 1500) / 500.0f * 120.0f * DEG_TO_RAD;
}

// ================= CORTE POR INCLINACION EXTREMA =================
const float DANGER_ANGLE_RAD = 45.0f * DEG_TO_RAD;
const int   DANGER_DEBOUNCE = 25; // ~100ms a 250Hz
int contadorPeligro = 0;
bool emergencia = false; // requiere desarmar (A=0) desde tierra para limpiar

// ---------------------------------------------------------------------
void aplicarPWM(int m1, int m2, int m3, int m4) {
    motor1.writeMicroseconds(constrain(m1, PWM_MIN_US, PWM_MAX_US) + desfaseM1);
    motor2.writeMicroseconds(constrain(m2, PWM_MIN_US, PWM_MAX_US) + desfaseM2);
    motor3.writeMicroseconds(constrain(m3, PWM_MIN_US, PWM_MAX_US) + desfaseM3);
    motor4.writeMicroseconds(constrain(m4, PWM_MIN_US, PWM_MAX_US) + desfaseM4);
}

void apagarMotores() {
    motor1.writeMicroseconds(PWM_MIN_US);
    motor2.writeMicroseconds(PWM_MIN_US);
    motor3.writeMicroseconds(PWM_MIN_US);
    motor4.writeMicroseconds(PWM_MIN_US);
}

void motoresIdle() {
    aplicarPWM(IDLE_US, IDLE_US, IDLE_US, IDLE_US);
}

// ================= CALIBRACION IMU AL ARRANQUE =================
// El dron debe estar QUIETO y NIVELADO. Promedia el giroscopio para sacar
// el bias, e inicializa rollEst/pitchEst con el acelerometro para que el
// filtro complementario no arranque desde cero si el piso no es perfecto.
void calibrarIMU() {
    const int N = 500;
    float sx = 0, sy = 0, sz = 0;
    sensors_event_t acc, gyr, temp;

    Serial.println("Calibrando IMU... NO MUEVAS EL DRON (3 s)");
    for (int i = 0; i < N; i++) {
        mpu.getEvent(&acc, &gyr, &temp);
        sx += gyr.gyro.x; sy += gyr.gyro.y; sz += gyr.gyro.z;
        // LED: barrido violeta mientras calibra
        if (i % 40 == 0) {
            aro.clear();
            aro.setPixelColor((i / 40) % NUM_LEDS, aro.Color(140, 0, 255));
            aro.show();
        }
        delay(5);
    }
    gyroBiasX = sx / N; gyroBiasY = sy / N; gyroBiasZ = sz / N;

    mpu.getEvent(&acc, &gyr, &temp);
    rollEst  = atan2(acc.acceleration.y, acc.acceleration.z);
    pitchEst = atan2(-acc.acceleration.x,
                      sqrt(acc.acceleration.y * acc.acceleration.y +
                           acc.acceleration.z * acc.acceleration.z));
    imuCalibrada = true;
    aro.clear(); aro.show();
    Serial.printf("IMU calibrada. Bias gyro [rad/s]: %.4f %.4f %.4f | roll0:%.1f pitch0:%.1f deg\n",
                  gyroBiasX, gyroBiasY, gyroBiasZ, rollEst * RAD_TO_DEG, pitchEst * RAD_TO_DEG);
}

// ================= INICIALIZACION DE ESCs =================
// Manda minimo sostenido para que los ESC armen (beeps) antes de aceptar
// cualquier modo. Los motores quedan LISTOS pero parados.
void inicializarESCs() {
    Serial.println("Inicializando ESCs (pulso minimo 3 s)...");
    unsigned long t0 = millis();
    while (millis() - t0 < 3000) {
        apagarMotores();
        // LED: barrido ambar
        aro.clear();
        aro.setPixelColor(((millis() - t0) / 250) % NUM_LEDS, aro.Color(255, 150, 0));
        aro.show();
        delay(20);
    }
    aro.clear(); aro.show();
    Serial.println("ESCs listos.");
}

// ---------------------------------------------------------------------
unsigned long ultimoDebug = 0;
unsigned long tPrevControl = 0;

void setup() {
    Serial.begin(115200);
    delay(500);

    // --- ESP-NOW primero ---
    WiFi.mode(WIFI_STA);
    WiFi.disconnect();
    if (esp_now_init() != ESP_OK) {
        Serial.println("Error critico: no se pudo inicializar ESP-NOW");
    }
    esp_now_register_recv_cb(onDataRecv);

    // --- NeoPixel ---
    aro.begin();
    aro.setBrightness(60);

    // --- ESCs: attach y secuencia de inicializacion ---
    motor1.attach(pinM1, PWM_MIN_US, PWM_MAX_US);
    motor2.attach(pinM2, PWM_MIN_US, PWM_MAX_US);
    motor3.attach(pinM3, PWM_MIN_US, PWM_MAX_US);
    motor4.attach(pinM4, PWM_MIN_US, PWM_MAX_US);
    inicializarESCs();

    // --- IMU + calibracion ---
    Wire.begin(SDA_PIN, SCL_PIN);
    mpuOK = mpu.begin();
    if (!mpuOK) {
        Serial.println("Error: MPU6050 no detectado. NO se podra armar.");
    } else {
        mpu.setAccelerometerRange(MPU6050_RANGE_8_G);
        mpu.setFilterBandwidth(MPU6050_BAND_10_HZ);
        calibrarIMU();
    }

    // --- PID / mezcladora ---
    pidRoll.Kp = Kp_ang;  pidRoll.Ki = Ki_ang;  pidRoll.Kd = Kd_ang;  pidRoll.N = N_filt;
    pidPitch.Kp = Kp_ang; pidPitch.Ki = Ki_ang; pidPitch.Kd = Kd_ang; pidPitch.N = N_filt;
    pidYaw.Kp = Kp_yaw;   pidYaw.Ki = Ki_yaw;
    construirMezcladora();

    Serial.println("Daltonics_Vuelo listo. Esperando modo desde Tierra:");
    Serial.println("  A=1 idle | A=2 despegue/hover | A=3 aterrizaje | A=0 desarmado");
    tPrevControl = micros();
}

// ---------------------------------------------------------------------
void loop() {
    unsigned long ahora = micros();
    float dt = (ahora - tPrevControl) / 1e6f;
    tPrevControl = ahora;
    if (dt <= 0 || dt > 0.5f) dt = 0.004f;

    // --- Failsafe: sin señal -> estado seguro (motores fuera) ---
    bool senalPerdida = (millis() - ultimaVezRecibido) > TIMEOUT_FAILSAFE;
    if (senalPerdida) {
        comandosDron.throttle = 1000;
        comandosDron.roll = 1500; comandosDron.pitch = 1500; comandosDron.yaw = 1500;
        comandosDron.armable = M_DESARMADO;
    }

    Modo modo = (Modo)comandosDron.armable;
    if (modo > M_ATERRIZAJE) modo = M_DESARMADO; // valor corrupto -> seguro

    // --- Reset de emergencia: tierra debe pasar por A=0 ---
    if (modo == M_DESARMADO) { emergencia = false; }

    // --- Leer IMU y estimar actitud (con bias restado) ---
    float yawRateMeas = 0;
    if (mpuOK) {
        sensors_event_t acc, gyr, temp;
        mpu.getEvent(&acc, &gyr, &temp);

        float gx = gyr.gyro.x - gyroBiasX;
        float gy = gyr.gyro.y - gyroBiasY;
        float gz = gyr.gyro.z - gyroBiasZ;

        float accelRoll  = atan2(acc.acceleration.y, acc.acceleration.z);
        float accelPitch = atan2(-acc.acceleration.x,
                                  sqrt(acc.acceleration.y * acc.acceleration.y +
                                       acc.acceleration.z * acc.acceleration.z));
        rollEst  = ALPHA * (rollEst  + gx * dt) + (1 - ALPHA) * accelRoll;
        pitchEst = ALPHA * (pitchEst + gy * dt) + (1 - ALPHA) * accelPitch;
        yawRateMeas = gz;

        if (fabs(rollEst) > DANGER_ANGLE_RAD || fabs(pitchEst) > DANGER_ANGLE_RAD) {
            contadorPeligro++;
            if (contadorPeligro >= DANGER_DEBOUNCE && (modo == M_VUELO || modo == M_ATERRIZAJE)) {
                emergencia = true;
                Serial.println("¡PELIGRO! Inclinacion extrema -> motores apagados.");
            }
        } else {
            contadorPeligro = 0;
        }
    }

    // --- Setpoints ---
    float thrCmdPct, rollRef, pitchRef, yawRateRef;
    leerSetpoints(thrCmdPct, rollRef, pitchRef, yawRateRef);

    bool puedeVolar = mpuOK && imuCalibrada && !senalPerdida && !emergencia;

    // =================== MAQUINA DE ESTADOS ===================
    if (!puedeVolar || modo == M_DESARMADO) {
        // ---------- DESARMADO / EMERGENCIA / FAILSAFE ----------
        apagarMotores();
        thrActual = 0;
        aterrizado = false;
        pidRoll.reset(); pidPitch.reset(); pidYaw.reset();

        if (emergencia)        aro.fill(aro.Color(255, 0, 0));   // rojo
        else if (senalPerdida) aro.fill(aro.Color(255, 60, 0));  // naranja
        else if (!mpuOK || !imuCalibrada) aro.fill(aro.Color(255, 0, 255)); // magenta
        else                   aro.fill(aro.Color(0, 40, 0));    // verde tenue

    } else if (modo == M_IDLE) {
        // ---------- IDLE: motores girando, sin despegar ----------
        motoresIdle();
        thrActual = (IDLE_US - PWM_MIN_US) / 10.0f; // % equivalente al idle
        aterrizado = false;
        pidRoll.reset(); pidPitch.reset(); pidYaw.reset();
        aro.fill(aro.Color(0, 255, 60)); // verde brillante = armado en idle

    } else {
        // ---------- VUELO (A=2) o ATERRIZAJE (A=3) ----------
        float thrObjetivo;
        if (modo == M_VUELO) {
            aterrizado = false;
            thrObjetivo = thrCmdPct; // gas objetivo desde tierra (hover +/- trim W/S)
        } else { // M_ATERRIZAJE
            if (thrActual <= PCT_CORTE_ATERR) aterrizado = true;
            thrObjetivo = aterrizado ? (IDLE_US - PWM_MIN_US) / 10.0f : 0.0f;
        }

        // Rampa de throttle (slew-rate)
        float maxSubida, maxBajada;
        if (modo == M_ATERRIZAJE && !aterrizado) {
            maxSubida = 0;                            // aterrizando no se sube
            maxBajada = RAMPA_ATERR_PCT_S * dt;
        } else {
            maxSubida = RAMPA_SUBIDA_PCT_S * dt;
            maxBajada = RAMPA_BAJADA_PCT_S * dt;
        }
        float delta = thrObjetivo - thrActual;
        if (delta >  maxSubida) delta =  maxSubida;
        if (delta < -maxBajada) delta = -maxBajada;
        thrActual += delta;

        if (modo == M_ATERRIZAJE && aterrizado) {
            // Ya toco piso (o gas bajo el minimo de sustentacion): idle
            motoresIdle();
            pidRoll.reset(); pidPitch.reset(); pidYaw.reset();
            aro.fill(aro.Color(0, 120, 255)); // celeste = aterrizado, en idle
        } else {
            // PID de actitud activo (en aterrizaje se mantiene nivelado
            // mientras baja: refs de roll/pitch siguen viniendo de tierra,
            // que en ese modo manda 0)
            float tauX = pidRoll.update(rollRef, rollEst, dt);
            float tauY = pidPitch.update(pitchRef, pitchEst, dt);
            float tauZ = pidYaw.update(yawRateRef, yawRateMeas, dt);

            float Ftotal = thrActual * (4.0f * TMAX / 100.0f);
            float u[4] = {Ftotal, tauX, tauY, tauZ};
            float T[4];
            for (int i = 0; i < 4; i++) {
                T[i] = Mix[i][0]*u[0] + Mix[i][1]*u[1] + Mix[i][2]*u[2] + Mix[i][3]*u[3];
                T[i] = constrain(T[i], 0.0f, TMAX);
            }
            int pulso[4];
            for (int i = 0; i < 4; i++)
                pulso[i] = (int)constrain(mapFloat(T[i], 0.0f, TMAX, PWM_MIN_US, PWM_MAX_US), PWM_MIN_US, PWM_MAX_US);
            aplicarPWM(pulso[0], pulso[1], pulso[2], pulso[3]);

            if (modo == M_VUELO) aro.fill(aro.Color(0, 150, 255));  // azul = volando
            else                 aro.fill(aro.Color(255, 255, 0));  // amarillo = aterrizando
        }
    }
    aro.show();

    // --- Telemetria hacia Tierra ~10 Hz ---
    if (macTierraCapturada && !peerTierraListo) {
        esp_now_peer_info_t peer = {};
        memcpy(peer.peer_addr, macTierra, 6);
        peer.channel = 0;
        peer.encrypt = false;
        if (esp_now_add_peer(&peer) == ESP_OK) peerTierraListo = true;
    }
    if (peerTierraListo && millis() - ultimoTelem > 100) {
        ultimoTelem = millis();
        PaqueteTelemetria tl;
        tl.rollDeg  = rollEst * RAD_TO_DEG;
        tl.pitchDeg = pitchEst * RAD_TO_DEG;
        tl.thrPct   = thrActual;
        tl.modo     = (uint8_t)modo;
        tl.flags    = (emergencia ? 1 : 0) | (senalPerdida ? 2 : 0) |
                      (aterrizado ? 4 : 0) | (mpuOK ? 8 : 0);
        esp_now_send(macTierra, (uint8_t *)&tl, sizeof(tl));
    }

    // --- Debug ~10 Hz ---
    if (millis() - ultimoDebug > 100) {
        ultimoDebug = millis();
        Serial.printf("MODO:%d FS:%d EMG:%d ATZ:%d | thr:%.1f%% obj:%.1f%% | roll:%.1f pitch:%.1f deg\n",
            modo, senalPerdida, emergencia, aterrizado,
            thrActual, thrCmdPct, rollEst * RAD_TO_DEG, pitchEst * RAD_TO_DEG);
    }

    delay(4); // ~200-250 Hz
}

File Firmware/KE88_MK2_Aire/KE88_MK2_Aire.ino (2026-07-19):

// =========================================================================
// KE88_MK2_Aire.ino — Firmware de vuelo (ESP32, unidad AIRE)
//
// Fase 1 del roadmap: PID embebido corriendo LOCALMENTE en este ESP32
// (no en MATLAB — el enlace ESP-NOW/Serial tiene demasiada latencia para
// un lazo de estabilizacion). MATLAB/el gemelo digital solo diseñan y
// validan las ganancias; aqui se portan a codigo.
//
// Reutiliza el protocolo (struct + failsafe) de ESP32_PRUEBAAIRE.ino para
// seguir siendo compatible con el emisor de tierra ya existente
// (ESP32_PRUEBATIERRA.ino). No modifica esos sketches ni el gemelo
// digital en Dron_Digital/MATLAB_DRIVE.
//
// Estado del proyecto al escribir esto: el chasis MK2 (600-1000 g)
// todavia no esta armado ni el MPU6050 montado, asi que varios valores
// abajo son PLACEHOLDERS marcados con "TODO" — se deben confirmar/medir
// antes de instalar helices.
// =========================================================================

#include <Arduino.h>
#include <WiFi.h>
#include <esp_now.h>
#include <Wire.h>
#include <Adafruit_MPU6050.h>
#include <Adafruit_Sensor.h>
#include <ESP32Servo.h>   // Instalar via Library Manager: "ESP32Servo"

// ---------------------------------------------------------------------
// Protocolo de comandos (identico a ESP32_PRUEBAAIRE.ino)
// ---------------------------------------------------------------------
struct __attribute__((packed)) PaqueteControl {
    uint16_t throttle;   // convencion RC: 1000-2000 us
    uint16_t roll;       // 1000-2000 us, centro 1500
    uint16_t pitch;      // 1000-2000 us, centro 1500
    uint16_t yaw;        // 1000-2000 us, centro 1500 (yaw-RATE, no angulo)
    uint8_t  armable;    // 0 = desarmado, 1 = armado
};

PaqueteControl comandosDron;
unsigned long ultimaVezRecibido = 0;
const unsigned long TIMEOUT_FAILSAFE = 500; // ms sin señal -> failsafe

void onDataRecv(const uint8_t *mac, const uint8_t *incomingData, int len) {
    if (len == sizeof(PaqueteControl)) {
        memcpy(&comandosDron, incomingData, sizeof(comandosDron));
        ultimaVezRecibido = millis();
    }
}

// ---------------------------------------------------------------------
// TODO (hardware): confirmar placa real. El comentario de
// ESP32_PRUEBAAIRE.ino dice "ESP32-C3", pero mpu650_serial_monitor.ino
// usa GPIO16/17 para I2C, que NO existen en un ESP32-C3. Los pines de
// abajo son los tipicos de un ESP32 devkit de 38 pines; si la placa real
// es un C3 Supermini, hay que cambiarlos (I2C tipico en C3: SDA=8, SCL=9,
// como en bme680_bluetooth.ino).
// ---------------------------------------------------------------------
#define SDA_PIN 21
#define SCL_PIN 22

const int PIN_ESC[4] = {13, 12, 14, 27}; // TODO: confirmar GPIO reales de cada ESC
// Orden de motores (igual que KE88_parametros.m, vista superior, x=adelante, y=izquierda):
//   M1 = delantero-izq (+x,+y)   M2 = delantero-der (+x,-y)
//   M3 = trasero-der   (-x,-y)   M4 = trasero-izq   (-x,+y)

const int PWM_MIN_US = 1000;  // ESC parado / calibracion minima
const int PWM_MAX_US = 2000;  // ESC empuje maximo

// ---------------------------------------------------------------------
// Geometria y empuje del chasis MK2 — TODO: medir en el chasis real.
// Placeholders tomados como referencia de orden de magnitud, NO validos
// para volar. dx/dy se miden centro->motor; Tmax es empuje maximo POR
// MOTOR en Newtons; c es el coeficiente de par de arrastre (ver
// KE88_parametros.m).
// ---------------------------------------------------------------------
float DX   = 0.09f;   // m  TODO: medir
float DY   = 0.09f;   // m  TODO: medir
float TMAX = 3.0f;    // N por motor  TODO: medir/estimar del datasheet del motor+helice
float CYAW = 0.012f;  // coef. par de arrastre  TODO: estimar

// ---------------------------------------------------------------------
// Ganancias PID — PLACEHOLDERS MUY CONSERVADORES a proposito.
// NO son las de KE88_parametros.m (esas son para un dron de 87 g).
// TODO: reemplazar con las ganancias que Control tunee en el gemelo
// digital MK2 (600-1000 g) antes de instalar helices.
// ---------------------------------------------------------------------
float Kp_ang = 0.0005f, Ki_ang = 0.0f,    Kd_ang = 0.0001f, N_filt = 20.0f;
float Kp_yaw = 0.0005f, Ki_yaw = 0.0f;

// ---------------------------------------------------------------------
// PID 2-DOF con derivada sobre la medicion (evita "derivative kick"),
// misma estructura que el bloque "PID Controller (2DOF)" usado en
// KE88_construir_modelo.m para PID_Roll y PID_Pitch (b=1, c=0).
// ---------------------------------------------------------------------
struct PID2DOF {
    float Kp, Ki, Kd, N;
    float integ = 0, dFilt = 0, prevMeas = 0;
    bool primed = false;

    float update(float ref, float meas, float dt) {
        if (!primed) { prevMeas = meas; primed = true; }
        float error = ref - meas;
        integ += Ki * error * dt;
        float rawDeriv = (meas - prevMeas) / dt;
        dFilt += (rawDeriv - dFilt) * constrain(N * dt, 0.0f, 1.0f);
        prevMeas = meas;
        return Kp * error + integ - Kd * dFilt;
    }
    void reset() { integ = 0; dFilt = 0; primed = false; }
};

// PI simple (yaw-rate), igual que el bloque "PID Controller" (Controller=PI)
// usado en PID_Yaw dentro de KE88_construir_modelo.m.
struct PIControlador {
    float Kp, Ki;
    float integ = 0;
    float update(float ref, float meas, float dt) {
        float error = ref - meas;
        integ += Ki * error * dt;
        return Kp * error + integ;
    }
    void reset() { integ = 0; }
};

PID2DOF pidRoll, pidPitch;
PIControlador pidYaw;

Adafruit_MPU6050 mpu;
Servo escs[4];

// Estimacion de actitud (filtro complementario)
float rollEst = 0, pitchEst = 0;   // rad
const float ALPHA = 0.98f;

// Mezcladora: Mix = inv(A), A construida igual que en KE88_parametros.m
float Mix[4][4];
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

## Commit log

2026-07-10 e corrigio la operacion de vuelo del dron como no volar debajo del suelo y modificar tiempo de vuelo a indefinido
2026-07-10 Corrección de estabilidad del Gemelo digital KE88
    [DronNaya.STL]
2026-07-12 Añadiendo carpeta de códigos y archivos .ino
2026-07-15 Se incluyen los archivos originales de diseño y el ensamblaje creados en SolidWorks para permitir la simulación del modelo en matlap
    [Brazos del dron.SLDPRT, DronSimulacion.SLDPRT, DrpnBASE.SLDPRT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]
2026-07-15 Se adjunta la imagen del banco de pruebas ya impreso en 3d con filamento PLA
2026-07-15 Actualización Readme - Compilación Betaflight-STM32F411
2026-07-16 Pruebas de comunicacion
2026-07-17 Estructura utilizada para cambiar el modelo del dron KE88 DRONE
    [FRONTPANEL.SLDPRT, Prueba 2.SLDPRT]
2026-07-19 Agregar firmware PID embebido para ESP32 Aire (KE88 MK2)
2026-07-19 Se adjunta el ensamblaje de dron final para la semana 3 con fin de hacer conexión de todos los componentes electrónicos al dron
    [Brazos del dron semana 3.SLDPRT, Elises de 16 cm.SLDPRT, Ensamblaje Dron semana 3.SLDASM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]
2026-07-22 Se adjunta el diseño mejorado de SolidWorks para implementar los siguientes componentes el microcontrolador ESP mini y la placa de distribución de potencia encargada de conectar todos los motores a l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
    [Brazos del dron semana 3.SLDPRT, Elises de 16 cm.SLDPRT, Ensamblaje Dron semana 3.SLDASM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]
2026-07-23 Implementación de controladores de tierra y aire para el dron en fisico (Testeo)
2026-07-23 Reorganiza archivos de ESP32, actualiza script de MATLAB y añade imagen MPU6050
2026-07-24 Vuelo con maquina de estados: idle, despegue/hover y aterrizaje por tecla
    - Firmware/Daltonics_Vuelo: calibracion de gyro al arranque, init de ESCs,
    modos A=0..3 (desarmado/idle/vuelo/aterrizaje), rampas de throttle,
    PID de actitud, failsafe y corte por inclinacion
    - CONTROL/Control_Vuelo_Daltonics.m: teclas E/T/L/Q + trim de gas W/S
    - CONTROL/Enviar_Mando_ESP32_Tierra.m: fix typo xfunction
    - DOCS/Procedimiento_Vuelo.md: checklist de prueba segura
    [Daltonics_Vuelo.ino]
2026-07-24 Mando de vuelo alineado al gemelo digital: +/-12 deg, +/-60 dps, tecla R hover
2026-07-24 Telemetria dron->operador: roll/pitch/gas/modo/alertas en vivo en MATLAB
    - Aire: envia PaqueteTelemetria a 10 Hz al MAC de Tierra (aprendido del
    primer paquete recibido, sin hardcodear)
    - Nuevo Firmware/Daltonics_Tierra: reenvia telemetria a MATLAB como TL,...
    - Mando MATLAB: muestra estado real del dron y alertas de emergencia
